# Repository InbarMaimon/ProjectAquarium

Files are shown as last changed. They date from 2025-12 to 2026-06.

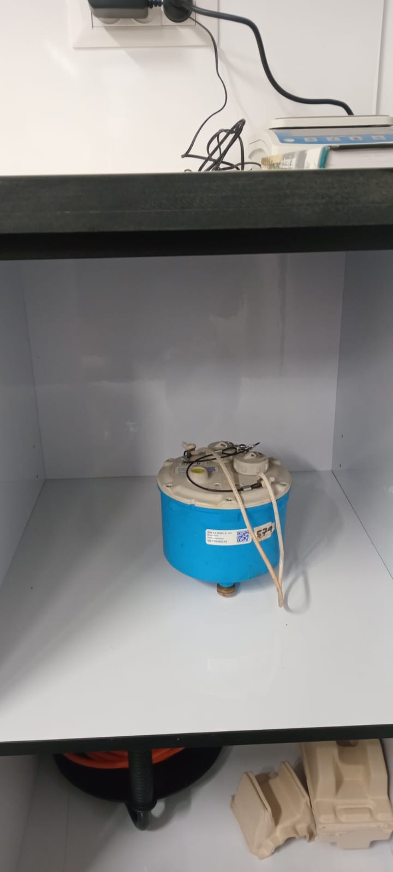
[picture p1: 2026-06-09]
images/seismographs/579-in-cabinet.jpeg

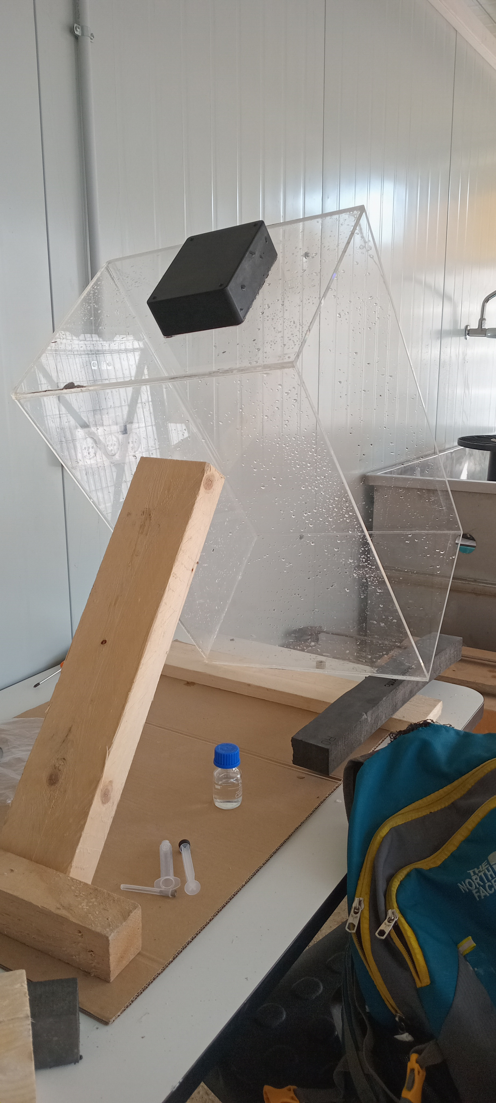
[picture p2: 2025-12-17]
images/aquarium/20251216_131820.jpg

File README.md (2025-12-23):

# Project Aquarium

Purpose:
Measure interaction between surfactants and capillary waves (ripples)

Structure:
- archive/      Junk that I don't have the heart to delete
- code/         Simulations, analysis
- data_raw/     Raw measurements
- data_proc/    Processed data
- design/       CAD, diagrams
- docs/         Theory
- images/       Photos of setup
- notes/         lab notes
- reports       Presentations, sum-ups, 
- results/      Figures, tables

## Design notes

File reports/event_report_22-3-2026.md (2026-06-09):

event report 22/3/2026

## short circuit
On the 18/3, Wednesday, I approached Tomer Brosh, the electrical engineer of the institute of earth sciences, and we connected the wiring of the motor circuit. Later in the lab I completed the circuit with the Raspberry Pi Pico (powered by my Thinkpad) and ran a short series of tests. mostly moving the coil statically up and down. The motor responded, though not cleanly. No further details.
While dissembling the circuit, I forgot to disconnect the power supply first. I loosened the screws that mount the motor and the power supply on the driver, and pulled out the + wire of the power supply. It touched the heads of the screws that mount the outputs of the motor. There was a short, part of the screw heads got brown, and the wire's terminal stuck to the head. I believe that at this point it disconnected the power and then separated the wire from the screw by applying a modest amount of force. Afterward I conncted the circuit again and it worked.

Measured today: 
resistance between the motor terminals: 1.6-1.7 ohm
diode resistance between the screws when the wires are disconnected is:

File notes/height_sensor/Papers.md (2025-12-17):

## A novel wave height sensor (Champan & Monaldo, 1993)
### 1.1 Questions

1. Accuracy of measurement, with respect to their reported sensitivity of $0.02 μ F ↔ 0.5 c m$ (small capacitance error corresponding to what is for us quite a large height error).
2. What is the circuit? Do we close it as usual from two sides of the wire? Is it a simple RC with square input or something more elaborate?
3. What exactly is the lower thickness limit of the oxide? How does leakage affect the capacitance, in a way that is not already reflected in the calibration curve? What is the optimal balance of minimizing leakage vs. maximizing capacitance in our system? How can we observe leakage from the standard capacitance measurement?
4. Self healing - shouldn’t happen exactly at the voltage of anodization? I’d think lower voltages will heal only a relatively deep crack. I saw $80V$ for anodization and $5V$ for healing.
5. On the other hand, why do we need a bias at all for valving? Isn’t it enough to input a positive bias for charging, with ground voltage for discharge?
6. How crucial will it be to know the exact salinity/chemistry of the water for calibration of the gauge? I think what we actually measure is the dielectricity of the excess water, and this I presume can depend strongly on its chemistry.
    
    \[The static dielectric constant (relative permittivity) of seawater is lower than pure water (around 80) and varies with temperature and salinity, but a common value used for open ocean conditions (around 20°C, 35 ppt salinity) is approximately 70-78\]
    
7. How important is it that the relationship between capacitance and local water height be linear? Isn’t a good (monotonic...) calibration curve enough?
8. Do we need fast charging for any reason but to save time?
9. What kinds of problems, noise sources etc. appear during simple measurements?
10. Verify no cross talks. In the paper they claim none down to $2 c m$ apart.

### 1.2 Idea

We want a non-intrusive way to measure wave height. The idea is to measure capacitance of a thin wire partly submerged in the water. If meniscus formed is small, the change in the wire capacitance (at the order of $μ F$ ) tracks the changes in the water height. Applying a DC offset signal keeps an anodizing process on, which self-heals damages to the oxide.

The wire is made of tantalum covered with its oxide ( $T a_2 O_5$ , made by submerging in citric acid), which is a good insulator.

The wire is connected to a circuit that feeds it with a square signal. Decay rate of the charge on the wire reports its capacitance. If the dielectric coating is uniform, the capacitance will change linearly with the height of the water.

### 1.3 Specifications

| parameter | size | comment |
| --- | --- | --- |
| tantalum wire diameter | $0.635 m m$ | the thinner the higher detection quality |
| corr. tensile strength | $70 k g m m ^{- 2}$ per $22 k g$ long. load | should taut the wire without tearing it  |

### 1.4 Manufacture process

1. Clean thoroughly in trichloroethane.
2. Rinse. Use gloves!
3. Put in citric acid under $0.5 m A c m ^{-2}$ (per total tantalum wire surface) DC up to $80 V$ , wherefrom the voltage is held constant, for __ minutes. **Smaller formation voltage generates thinner oxide layer.** Anodizing configuration:
    
    1. A trough long enough to hold the required wire including edge locking, with wire support glued to the bottom near both ends and terminal strips at the ends.
    2. A ground $6 m m$ stainless steel wire at the bottom of the trough.
    3. Rinsed tantalum wires strung near the top of the trough through the supports and terminals.
    4. $0.01\%$ citric acid solution that was stirred for several hours and then equilibrated over 24 hours.
    
    At constant voltage, perfect insulation will give 0 current. Hence minimal current (before excess defects develop) corresponds to best isolation. May try to replace electrolyte solution with cleaner one if leakage is above $0.005 m A c m ^{-2}$ (again proportional to total wire interface).
    
4. Rinse.
5. Cut the wire at the support positions.
6. Dry.
7. Observe metallic purple color. Hue indicates thickness, as the color is the result of thin film interference. [Observe effect of bending.]
    
    Remark 1. In the paper, they got $3.2 μ F m ^{-1}$ , I think per wire.

### 1.5 Circuit

The wire takes as an input a square waveform, that is, an alternating charge and discharge of the capacitor.

### 1.6 Digitization

Make sure that the digitization is good enough to measure the full scale height to voltage from the circuit.

### 1.7 Operation

1. Soak in target water for $30 m i n$ to relax initial drift processes, associated with crystallization of the oxide. \[Maybe I want to test that.\]

* As per their fig. 7, at $25 c m$ water depth and with a $3 c m$ diameter electronics tube at the bottom, the trend is already robustly linear at still water.

* Deviation from linear trend should be of the order of $± 0.05 μ F$ for capacitance of $∼ 0.1 - 10 μ F$. They report an error of 0.5 c m for static depth in the range $25 - 300 c m$ . We need something more sensitive.

* Frequency response should drop down $∼ 3 d B$ at $16 H z$, so we do not expect to measure very small ripples.  

* We should recalibrate the system once every two weeks or so to see that the capacitance-to-height slope didn’t change significantly.

* Notice not to allow resonance between capillaries and wires.

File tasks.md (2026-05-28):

### Back to Business
Draw on some board the various tasks that need to be handled. That would be:
  a. The Boson
  b. The big container
  c. The seismic analysis
  d. The height sensor
  e. The aquarium's structure
  f. The wave maker
  g. The alternative height sensor

### Administrative
1. Access to printer.
2. On Sunday/Monday morning, talk to Helena about internet connection in the shed.

### General
1. Learn git and absorb into workflow.

### Science
1. Overview of spectrum of sea water capillary with various surfactants.
1. Finish reading Zappa's paper about amplitudes/slopes of capillary waves.

### Boson
1. Go through the state of the code, write down here what we can and cannot do.
2. A new pin for the box?
3. See that I know where the parts are.

### Aquarium
1. Clean the shed.
2. Go through the code, see where we're at.
3. What was the state of the vibration analysis?
4. Understand how to lock the aquarium in place, and width of bridges.

### Wave maker
1. Review the parts that we have.
2. Make a complete scheme of the plunger solution.
3. Once we settle on a complete solution, including exact parts, talk to Tomer/Yosi again about it.
4. Reach out to Itsik for construction

### Height sensor
1. Verify that the capacitive gauge satisfies our sensitivity requirements.
2. Review the logs from the height sensor manufacturing.
3. Capacitive gauge making.
 
```mermaid
flowchart TD
    START[Start] --> HEIGHT([Height sensor: physical requirements & pricing])
    START[Start] --> WM_T([Wave making theory])
    START[Start] --> STG[Permanent stage for the aquarium]

    STG --> HB[Bridge for the height sensor]
    STG --> WMB[Bridge for the wave maker]

    HEIGHT --> SENS_SEL{Select Sensor Type}
    
    WM_T --> WM_SD[required stroke depth: ~2-20mm];
    RG1[research goals: inspect gravity-capillary waves] --> WM_GF[required frequencies: ~5-30Hz];
    RG2[research goals regarding type of interactions] --> Meas_MD[measurement distance where standing waves vanish: 30cm is more than enough]

    WM_T --> Meas_MD
    WM_SD --> WM_CM[Choose motor];
    WM_GF --> WM_CM;
    WM_CM --> WM_F[Design system];
    WM_CM --> WM_C[Choose controller]
    WM_F --> WM_G[Get pricing];
    WM_G --> WM_H[Build system];

    SENS_SEL -->|Capacitive| CAP_DESIGN[Design]
    SENS_SEL -->|Laser| LASER([Design])

    CAP_DESIGN --> COMM_DES[Design<br/>connections]
    CAP_DESIGN --> CAP_LEN[Decide wire<br/>length & quantity]
    CAP_DESIGN --> ELEC_DES[fit<br/>terminal strip]
    CAP_DESIGN --> HOLD_SOL[Decide<br/>holder solution]

    WM_C --> COMM_DES[Design<br/>connections]

    CAP_LEN --> TROUGH_DER[Derive<br/>trough length]
    
    TROUGH_DER --> PROCURE[Buy pipe,<br/>SS rod/wire, holder<br/>material, citric acid]
    ELEC_DES --> PROCURE
    HOLD_SOL --> PROCURE
    
    PROCURE --> CUT_PARTS[Cut trough<br/>& holders, leave<br/>rod path]
    
    CUT_PARTS --> GLUE_HOLD[Glue<br/>holders]
    
    GLUE_HOLD --> GET_VSRC[Get smart<br/>voltage source]
    GLUE_HOLD --> GET_H2O[Get<br/>pure water]
    
    GET_VSRC --> GND_ROD[Place ground<br/>SS rod & connect<br/>to source]
    GET_H2O --> GND_ROD
    
    GND_ROD --> WIRE_MOUNT[Mount<br/>wires on holders &<br/>connect to terminal]
    
    WIRE_MOUNT --> TERM_CONN[Connect<br/>terminal to source]
    
    TERM_CONN --> OBSERVE[Observe<br/>result]

    LASER --> COMM_DES
    LASER --> RANGE[Height range: 10-30mm]
    LASER --> SPOT[Spot diameter: 1-5mm]
    LASER --> VIB_RES[Stability in frequency range: 5-30Hz]
    LASER --> TRANS[Reflects well from water?]
    LASER --> SAMP[Verify sampling rate]
```

### Camera
1. Study camera software.
2. Measure width of container.
3. Order/build mount (including weight) + pitch axis + how to measure the pitch.
4. Verify camera screws fine to mount.

### Possible schedule clashes
I think there should be none. The gauge should be non-intrusive, but the assemble is very simple.

## periodically

### daily note
- what was done
- what is to be done tomorrow

### git
Edit → Add → Commit → Push

This is the project backup workflow. All tracked files, including moved or renamed files, are preserved both locally and on GitHub.

1. Daily / session work
Edit files as needed (code, documentation, data notes).
Add new files or moved files to Git tracking:

    git add <file_or_folder>

or to add everything modified/untracked:

    git add .gitignore README.md docs project_env.sh   // ignore until we have a stable version

2. Commit changes
Commit logically grouped changes with a clear message:

    git commit [--amend] -m "Daily: [changes I've made]"

Commit at the end of each logical task or end-of-day. This keeps your history clean.

3. Push to GitHub
Upload local commits to the online backup:

    git push [--force-with-lease // if --amend was done.]

After this, your local repository and the remote repository are in sync.
GitHub now acts as a full backup of all tracked files and history.

4. Optional: Pull before starting work on another machine
If you work on multiple machines:

git pull

Ensures you have the latest state before editing.

5. Best practices

- Commit small, logical changes rather than massive, vague commits.
- Track only what matters (use .gitignore to skip temporary files, generated data, and .obsidian).
- Do not push large raw data files if they exceed GitHub limits; keep them local or use Git LFS.
Tag stable milestones (optional):

git tag v1.0
git push --tags

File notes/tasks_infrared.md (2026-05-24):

## Capacitance gauge 
- report the anodization process.
- add block diagram with comments of capacitor to computer line
- add pictures of the parts

## Infrared:

- find a replacement for the missing screw

- ask Maly about purchase of towels, IPA99, clean air pressure bottles.

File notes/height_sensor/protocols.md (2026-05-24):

### Citric acid making protocol
#### Materials:
- goggles
- gloves
- coat
- solid citric acid
- small powder holder
- fine-scale weight
- acid container
- acid waste collector
- water source

#### Procedure:
1. put coat, eye shield, gloves.
2. weigh 0.1g of citric acid.
3. weigh 1 liter of tap/deionized water
4. pour a small amount of water
5. put the acid
6. wash the rest of acid with water
7. seal the bottle and shake
8. pour the rest of the water
9. seal and shake
10. acid holder to garbage
11. make sure you left enough space in the bottle for pressure to not overbuild,
or othewise loosen the lid slightly.
12. mix on the shaker for an hour
13. take of the shaker, let it stand the night in the fume hood.
Might be slightly open.

### Anodization protocol
#### Materials:
- goggles
- gloves
- coat
- trough with tantalum wires mounted straight.
- power generator with power cable.
- black and red crocodile cables
- ampermeter
- male-male cables as needed
- acetone
- acid in container
- clean paper towel
- acid waste collector
- meter
- pliers or 1 plier and 1 melkhatzayim

#### Procedure:
1. Straighten the wires as much as possible.
2. Cut large enough pieces to fit nicely in the holder + exposed side.
3. Put goggles and gloves.
4. Clean everything with acetone and tap water. Also gloves.
5. Put the trough in the hood on a clean plate, preferably with a clean paper in between.
6. Put the power generator beside it but away, so that no acid spill can easily reach it.
7. Mount the wires in the holder.
8. Gently put the holder in place and close the screws.
9. Write formation voltage used.
10. Connect the power generator to socket, set max current on required mA limit value (can be more exact if power generator allows) and voltage on maximum.
11. Fill the trough with citric acid.
12. Connect the + to the tantalum and the - to the stainless steel. 
13. Connect a resisor in series.
14. Connect a voltmeter/raspberry pi voltage sensor on it.
15. Turn on the ports.
16. Write the time of start.
17. Write time of formation voltage.
18. Write time of minimum current.
19. (If we go for anodization sealing, fill a small amount of citric acid back into the trough and put the end of the cut wires in it, connect + and - and anodize up to formation voltage.)
20. Disconnect the circuit and carefully collect the + and - wires. If needed, clean them with a damp paper towel, then with a dry one. 
21. Disconnect the power generator from socket. If needed, clean cable and generator with damp and dry paper.
22. If anodization is done, put generator in place.
23. Prepare a clean sheet of paper for to put cleaned trough parts and wires to dry.
24. Spill the wasted acid to acid collector. Mark it if needed.
25. Disassemble the trough. Be careful with the anodized wires!
26. Clean the trough parts with tap/deionized water.
27. Store/pack acid container.
28. Return goggles, coat to place.

### Quick capacity check
#### Material:
- gloves
- a small cup
- a capacitance meter and +- wires
- anodized tantalum wire
- meter/ruler
- deionized/tap water source
#### Procedure:
1. Cut the anodized wire.
2. Cover the end with some temporary isolator.
3. Rinse the wire in deionized water.
4. Prepare a cup with tap water in it.
5. Connect anodized wire to +.
6. Connect an exposed wire to -.
7. If tips are not isolated, make sure the multimeter works at voltage below 1V, so that the natural oxide at the tip can serve as a (partial) isolation.
8. Formation voltage vs. capacitance:
   1. 60V -> ~ (2.0-6.8)[nF/mm]
   2. 80V -> ~ (1.5-5.1)[nF/mm]
   3. 120V -> ~ (1.0-3.4)[nF/mm] (!!!Avoid because of risk of scintillation!!!)

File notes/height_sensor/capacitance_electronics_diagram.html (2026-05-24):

## Aquarium Sensor — Electronics Block Diagram

flowchart TB subgraph SENSORS["Sensors (in aquarium)"] TA1["Ta wire 1\nCapacitor"] TA2["Ta wire 2\nCapacitor"] TA3["Ta wire 3\nCapacitor"] end subgraph BOX["Electronics box (on mounting plate)"] CDC["CDC Board\nScioSense PCAP04\n\nMeasures capacitance\nof each Ta wire"] PICO["PS2→USB Interpreter\nPicoprog\n\nConverts CDC output\nto USB HID"] end PC["Windows Computer\nReads USB HID data"] TA1 -->|"analog\n(short wire)"| CDC TA2 -->|"analog\n(short wire)"| CDC TA3 -->|"analog\n(short wire)"| CDC CDC -->|"SPI / I²C\n(digital)"| PICO PICO -->|"USB\n(digital, long cable OK)"| PC style SENSORS fill:#fff3e0,stroke:#e65100,stroke-width:2px,color:#333 style BOX fill:#e3f2fd,stroke:#01579b,stroke-width:2px,color:#333 style TA1 fill:#ffccbc,stroke:#bf360c,color:#333 style TA2 fill:#ffccbc,stroke:#bf360c,color:#333 style TA3 fill:#ffccbc,stroke:#bf360c,color:#333 style CDC fill:#bbdefb,stroke:#01579b,color:#333 style PICO fill:#bbdefb,stroke:#01579b,color:#333 style PC fill:#c8e6c9,stroke:#1b5e20,color:#333

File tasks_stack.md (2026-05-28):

### Now
We want to estimate the physical parameters of the capillary waves we set to observe.
For this we need to know:
1. Their height spectrum - the expected amplitude as a function of wavenumber/frequency.
2. In particular, if and where there's a high cutoff.
Next, we want to understand the theoretical dispersion so we need to:
1. Implement the code for a fitting model (happened?).
2. Estimate the parameter values (complex elasticity etc.) for various conditions: compile a small library of parameters by surfactant type.
3. Plot the contribution of various components, if extractable, against wavenumber/frequency.

### Wendesday morning
1. To Mali if she has a documentation of what I've bought from the main warehouse.
2. Go to the main warehouse and get air, Isopropyl alcohol (IPA) 99% and fitting towels. Cotton swab?
3. Call Shahaf or Eran about the screw.
4. Clean the box's window.

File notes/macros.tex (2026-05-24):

% ============================================================
% Macros (converted from macros.lyx)
% ============================================================

\newcommand{\entropy}{\eta}

\newcommand{\surfaceTension}{\tau}
\newcommand{\sTension}{\surfaceTension}

\newcommand{\surfaceWaterDensity}{\rho}
\newcommand{\sDensity}{\surfaceWaterDensity}

\newcommand{\stressTensor}{\sigma}

\newcommand{\surfacePressure}{p_{0}}
\newcommand{\sPressure}{\surfacePressure}

\newcommand{\surfactantBulkConcentration}{c}
\newcommand{\sBulkCo}{\surfactantBulkConcentration}

\newcommand{\surfactantSurfaceConcentration}{s}
\newcommand{\sSurfCo}{\surfactantSurfaceConcentration}

\newcommand{\velocityPotential}{f}
\newcommand{\vPotential}{\phi}
\newcommand{\vStream}{\psi}

\newcommand{\kinematicViscousity}{\nu}

\newcommand{\kTravel}{k_{p}}
\newcommand{\kevanescentn}{k_{e,n}}
\newcommand{\kEvanescentn}{k_{e,n}}

\newcommand{\aquariumHeight}{H}
\newcommand{\aquariumLength}{L}
\newcommand{\aquariumWidth}{W}
\newcommand{\aHeight}{\aquariumHeight}
\newcommand{\aLength}{\aquariumLength}
\newcommand{\aWidth}{\aquariumWidth}

\newcommand{\baseVel}{u}

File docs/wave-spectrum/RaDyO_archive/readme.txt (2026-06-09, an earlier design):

**********
**README**
**********

The attached '.mat' files contain full spectra and probability density functions computed from the short wave fields observed during the 2008 RaDyO campaign. Water surface elevation time series from the Riegl lidar are provided (with dimensions of meters).

For all files:

k - wavenumber in rad/m
B - omnidirectional saturation spectrum in rad
ustar - friction velocity u* in m/s

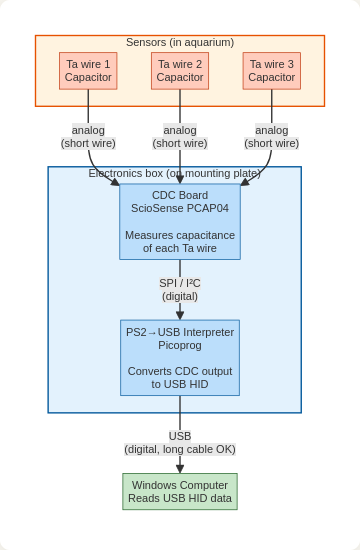
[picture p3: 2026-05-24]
notes/height_sensor/capacitance_electronics_diagram.png

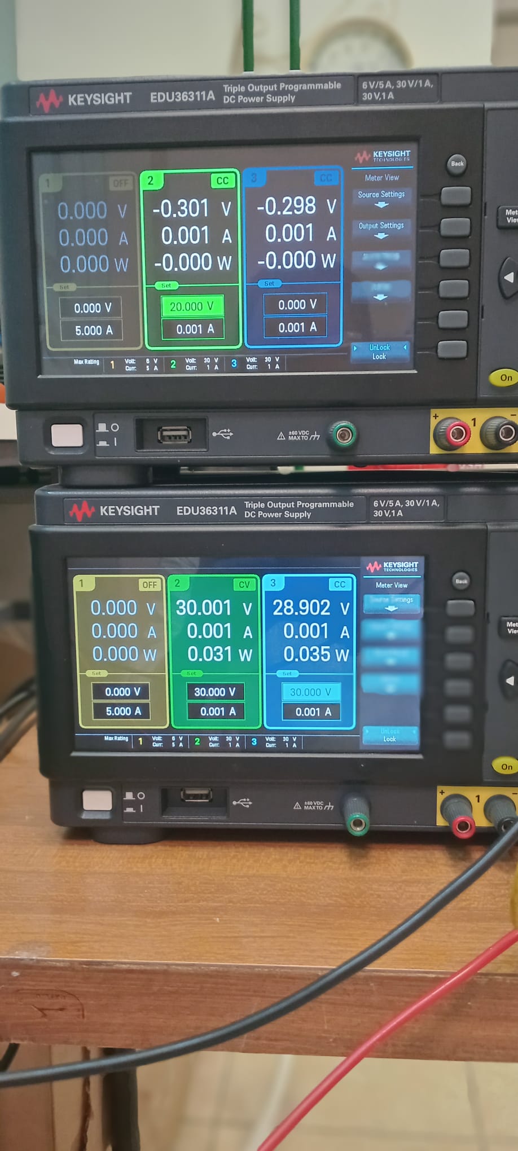
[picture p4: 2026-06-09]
images/anodization/typical-reading-of-generator.jpeg

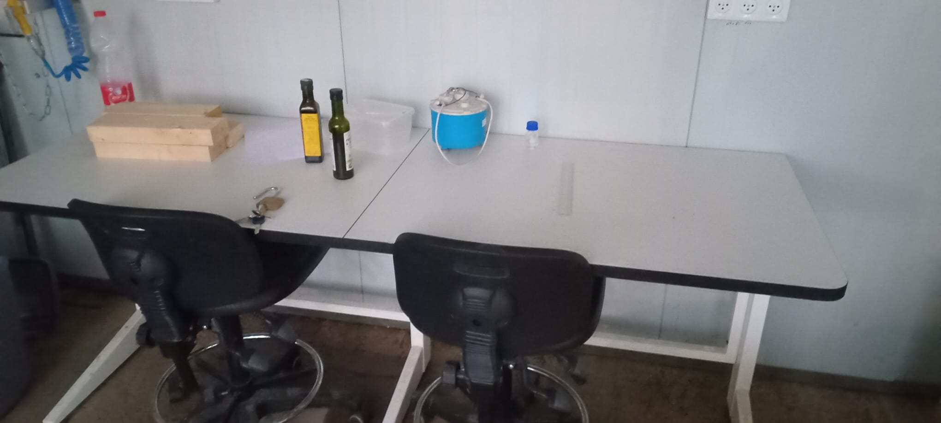
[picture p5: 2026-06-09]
images/seismographs/583-on-desk.jpeg

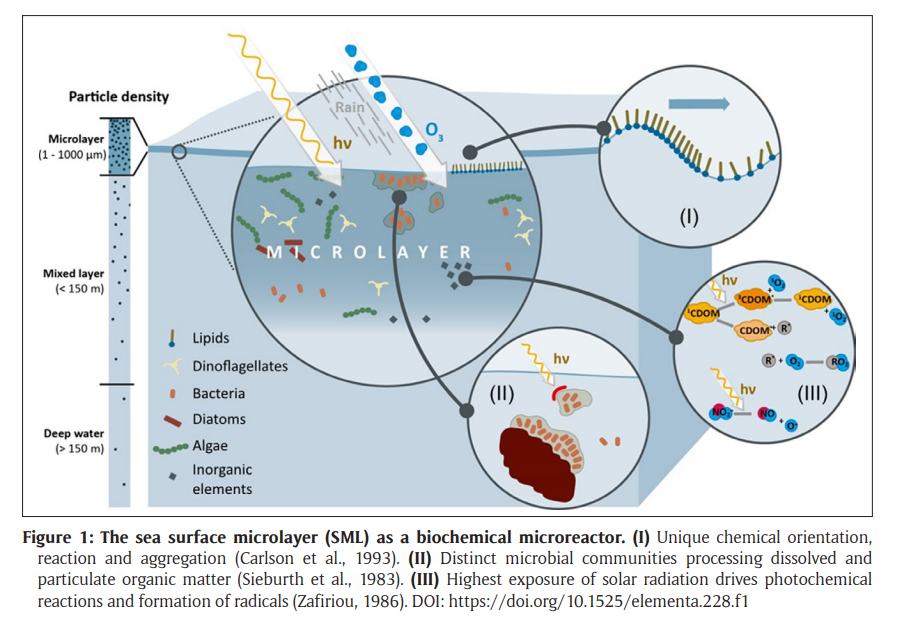
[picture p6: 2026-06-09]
docs/Wurl - Sea surface microlayer in a changing ocean - figure 1.png

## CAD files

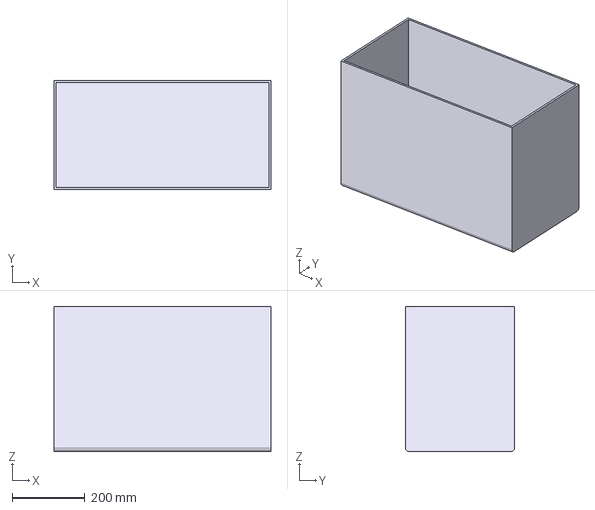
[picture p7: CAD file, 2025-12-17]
design/aquarium/aquarium-Body.step
598.5 x 301.0 x 400.0 mm

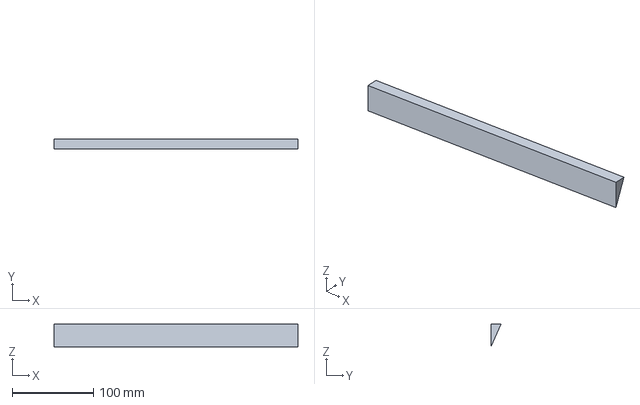
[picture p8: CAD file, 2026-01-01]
design/wave_maker/wavemaker_model.FCStd
300.0 x 12.4 x 27.8 mm

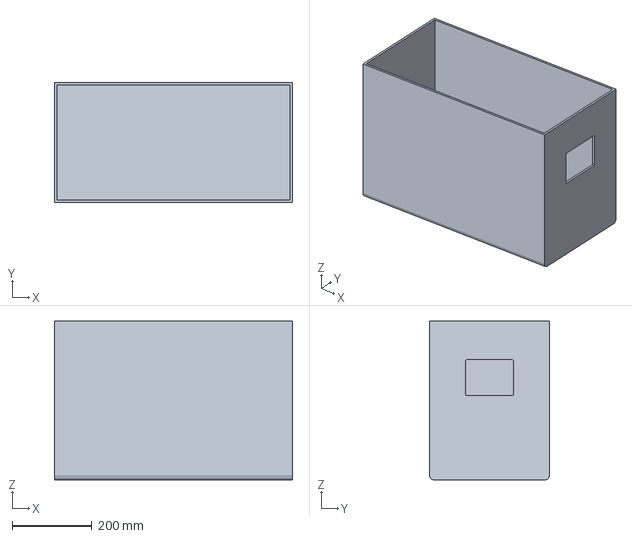
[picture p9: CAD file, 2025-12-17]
design/aquarium/aquarium.FCStd
598.5 x 301.0 x 399.0 mm

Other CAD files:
design/aquarium/aquarium-Body.3mf

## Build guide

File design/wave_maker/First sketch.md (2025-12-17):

1. Stepper motor generates constant roll:
    1. Understand size, shape, weight and price.
    2. Understand whether comes with a controller, or cont. comes separately, and how I communicate with the controller.
    3. If needed: purchase an Arduino and learn how to work with it.
    
2. Crankshaft converts to linear motion:
    1. Learn FreeCad and download/make a model.
    2. Order two bearings that connect the conrod to the piston/screw and to the disc.
    3. Check weights of suggested plungers and verify that the piston can connect to them and that the plastic carries well the load.
    
3. Connect a plunger head:
    1. Find a vertical plunger model that excites minimal number of modes.
    2. Understand how to mount it on the piston.
    3. Print crankshaft somewhere in the university and assemble.

4. Mount on aquarium:
    1. Clean the aquarium.
    2. Glue it - how?
    3. Plan a bridge with mount for the motor and crankshaft.
    4. Get it.

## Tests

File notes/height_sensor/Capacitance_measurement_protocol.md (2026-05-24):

## Capacitance measurement protocol

### Preliminary requirements:
- The capacitive gauge wires are mounted stretched in a robust manner.
- How to read a data file.
- How is the data saved in real time?
- What is the external offset? Is it stable under mild perturbations? (introduce manually)
- Can I measure external offset during a run?

### Linearization

### Run
- External capacitive offset: measure once, before experiment, at varying temperatures if possible. Make sure that the physical configuration doesn't change significantly during the experiment.

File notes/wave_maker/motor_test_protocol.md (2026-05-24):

## order of assemble:
1. Make a clean surface with room for motor, driver and controller.
2. Put the power supply in an accessible position far from everything else.
3. Put the motor gently with pin up.
4. Put the driver nearby.
5. Connect the PS wires to the driver. Make sure that - (blue) goes to GND and + (brown) goes to VIN. Screw them.
6. Connect the motor wires to the driver. Make sure that OUTA (red) goes to OUTA and OUTB (black) goes to OUTB.
7. Put the Pico nearby, legs up.
8. Wiring:
  GP0  → [brown] → 810-01 PWM pin
  GP1  → [orange] → 810-01 DIR pin
  GP2  → [white] → 810-01 RESET pin  (active LOW: pull low to disable driver)
  GND  → [black] → 810-01 Logic GND
9. Connect Pico to computer.
10. Connect Pico to VS code interface.
11. Download current image of the test files.
12. Verify that everything is there using os.listdir().
13. Connect power.
14. Set duty to 0, enable, set duty to 5%, observe lift.
15. Play.

## order of dissemble:
1. Set duty to 0, observe the magnet falls back to place, disable.
2. Assemble in reverse.

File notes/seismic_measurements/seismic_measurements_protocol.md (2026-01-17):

protocol

14.1 ~14:00 - One day on the table / in the lab on table
15.1 14:00 - Move one whole meter along each axis, then return to place.
+ three days on the table / three days in the lab on table
18.1 14:00
one day on the ground inside shed / in the lab on the ground

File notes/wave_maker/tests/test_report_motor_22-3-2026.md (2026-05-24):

I connected the circuit. Motor was placed with its pin up.
Initially I switched the GND and RESET wires. Rewired correctly afterward.
I tried the sine function input at 4.3% offset, 2% (voltage) amplitude and 1000ms period. The motor moves up and down regularly but nonsinusoidally, with the uplift looking sharper than the downglide and the movement overall rather constant in velocity.
I also tried 4.3% 4% 40ms and 20ms. The movement looks and sounds irregular.

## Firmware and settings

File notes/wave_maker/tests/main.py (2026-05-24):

"""
moticont_hold.py
----------------
Raspberry Pi Pico 2W  →  Moticont 810-01 driver  →  GVCM-015-025-01

Wiring:
  GP0  → [brown] → 810-01 PWM pin
  GP1  → [orange] → 810-01 DIR pin
  GP2  → [white] → 810-01 RESET pin  (active LOW: pull low to disable driver)
  GND  → [black] → 810-01 Logic GND

PWM frequency : 20 kHz  (inaudible, well within driver 50 kHz max)
Control       : USB serial (115200 baud) — connect with any terminal
                e.g.  screen /dev/ttyACM0 115200
                      PuTTY, Thonny REPL, etc.

Serial commands (case-insensitive):
  enable          - release RESET, driver becomes active
  disable         - assert RESET, driver disabled (coil de-energised)
  duty <0-100>    - set PWM duty cycle as a percentage  e.g. "duty 35"
  dir <0|1>       - set direction  (0 = OUTB→OUTA, 1 = OUTA→OUTB)
  status          - print current duty, direction, and enable state

Notes:
  - This is open-loop. Start with a LOW duty cycle (~10-20%) and increase
    slowly until the coil holds position against gravity. Exceeding the
    motor's continuous current rating will cause overheating.
  - GVCM-051-025-01 continuous force is modest; don't run at 100% duty
    for extended periods without checking motor temperature.
  - The RESET pin is active-LOW on the 810-01. Driving GP2 HIGH releases
    the driver; driving it LOW disables it.
"""

import sys
import select
from tests_vc import handle_line

# ---------------------------------------------------------------------------
# Boot banner
# ---------------------------------------------------------------------------
print("=" * 50)
print("  Moticont GVCM-015-025-01 / 810-01 hold controller")
print("  Pico 2W  |  20 kHz PWM  |  GP0=PWM  GP1=DIR  GP2=RESET")
print("  Driver is DISABLED on boot. Send 'enable' to start.")
print("  Type 'status' for current settings.")
print("=" * 50)

# ---------------------------------------------------------------------------
# Main loop — non-blocking USB serial read
# ---------------------------------------------------------------------------
buf = ""

while True:
    # Poll stdin without blocking (works on Pico USB serial)
    if sys.stdin in select.select([sys.stdin], [], [], 0)[0]:
        ch = sys.stdin.read(1)
        if ch in ("\r", "\n"):
            if buf:
                handle_line(buf)
                buf = ""
            else:
                continue
        elif ch == "\x08":   # backspace
            buf = buf[:-1]
        else:
            buf += ch

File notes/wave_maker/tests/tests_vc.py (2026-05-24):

import sys
import select
import time
import math
from machine import Pin, PWM

# ---------------------------------------------------------------------------
# Pin assignments
# ---------------------------------------------------------------------------
PIN_PWM   = 0   # GP0 → 810-01 PWM input
PIN_DIR   = 1   # GP1 → 810-01 DIR input
PIN_RESET = 2   # GP2 → 810-01 RESET input (HIGH = run, LOW = disabled)

# ---------------------------------------------------------------------------
# PWM configuration
# ---------------------------------------------------------------------------
PWM_FREQ_HZ = 20_000   # 20 kHz — inaudible, within driver spec

# ---------------------------------------------------------------------------
# Default motion parameters  (edit these as a starting point)
# ---------------------------------------------------------------------------
DEFAULT_DUTY_PERCENT = 0    # Start at 0%; increase via serial once enabled
DEFAULT_DIRECTION    = 1    # 1 = OUTA→OUTB; pushes outward

# ---------------------------------------------------------------------------
# Hardware initialisation
# ---------------------------------------------------------------------------
pwm = PWM(Pin(PIN_PWM))
pwm.freq(PWM_FREQ_HZ)

dir_pin   = Pin(PIN_DIR,   Pin.OUT)
reset_pin = Pin(PIN_RESET, Pin.OUT)

# Helpers
def _duty_u16(percent: float) -> int:
    """Convert 0–100 % to 0–65535 for machine.PWM.duty_u16()."""
    return int(max(0.0, min(100.0, percent)) / 100.0 * 65535)

# ---------------------------------------------------------------------------
# State
# ---------------------------------------------------------------------------
state = {
    "enabled": False,
    "duty":    DEFAULT_DUTY_PERCENT,
    "dir":     DEFAULT_DIRECTION,
}

def _apply_state():
    """Push current state to hardware."""
    dir_pin.value(state["dir"])
    pwm.duty_u16(_duty_u16(state["duty"]) if state["enabled"] else 0)
    # RESET pin: HIGH = driver active, LOW = driver disabled
    reset_pin.value(1 if state["enabled"] else 0)

# Start safe: driver in reset, zero PWM
_apply_state()

# ---------------------------------------------------------------------------
# Command handlers
# ---------------------------------------------------------------------------
def cmd_enable(_args):
    state["enabled"] = True
    _apply_state()
    return f"Driver ENABLED  |  duty={state['duty']:.1f}%  dir={state['dir']}"

def cmd_disable(_args):
    state["enabled"] = False
    _apply_state()
    return "Driver DISABLED  (coil de-energised, RESET asserted)"

def cmd_duty(args):
    if not args:
        return "ERROR: usage:  duty <0-100>"
    try:
        val = float(args[0])
    except ValueError:
        return "ERROR: duty value must be a number 0–100"
    if not (0 <= val <= 100):
        return "ERROR: duty must be between 0 and 100"
    state["duty"] = val
    if state["enabled"]:
        pwm.duty_u16(_duty_u16(val))
    return f"Duty set to {val:.1f}%  {'(applied)' if state['enabled'] else '(staged — enable driver to apply)'}"

def cmd_sine(args):
    """sine [center_%] [amplitude_%] [period_ms]
    Oscillates duty cycle as:  center + amplitude * sin(t)
    Defaults: center=4  amplitude=1  period=2000ms
    Send any serial character to stop.
    """

    try:
        center    = float(args[0]) if len(args) > 0 else 4.0
        amplitude = float(args[1]) if len(args) > 1 else 1.0
        period_ms = float(args[2]) if len(args) > 2 else 2000.0
    except ValueError:
        return "ERROR: usage:  sine [center_%] [amplitude_%] [period_ms]"
 
    if not state["enabled"]:
        return "ERROR: driver not enabled — send 'enable' first"
 
    max_duty = center + amplitude
    if max_duty > 25:
        return f"ERROR: center+amplitude={max_duty:.1f}% exceeds 25% continuous limit at 24V"
 
    print(f"Sine running: center={center}%  amplitude={amplitude}%  period={period_ms}ms")
    print("Send any key to stop.")
 
    step_ms   = 1                           # update every 1ms → 1kHz
    steps     = int(period_ms / step_ms)    # steps per full cycle
    i         = 0
 
    while True:
        # Check for keypress to stop
        if sys.stdin in select.select([sys.stdin], [], [], 0)[0]:
            sys.stdin.read(1)               # consume the character
            break
        angle    = 2 * math.pi * (i % steps) / steps
        duty_pct = center + amplitude * math.sin(angle)
        pwm.duty_u16(_duty_u16(duty_pct))
        time.sleep(step_ms / 1000)
        i += 1
 
    # Restore previous duty on exit
    pwm.duty_u16(_duty_u16(state["duty"]))
    return f"Sine stopped. Duty restored to {state['duty']:.1f}%"

def cmd_dir(args):
    if not args or args[0] not in ("0", "1"):
        return "ERROR: usage:  dir <0|1>"
    state["dir"] = int(args[0])
    if state["enabled"]:
        dir_pin.value(state["dir"])
    return f"Direction set to {state['dir']}  {'(applied)' if state['enabled'] else '(staged — enable driver to apply)'}"

def cmd_status(_args):
    lines = [
        "--- Status ---",
        f"  Enabled  : {state['enabled']}",
        f"  Duty     : {state['duty']:.1f}%",
        f"  Direction: {state['dir']}  (0=OUTB→OUTA  1=OUTA→OUTB)",
        f"  PWM freq : {PWM_FREQ_HZ} Hz",
    ]
    return "\n".join(lines)

COMMANDS = {
    "enable":  cmd_enable,
    "disable": cmd_disable,
    "duty":    cmd_duty,
    "sine":    cmd_sine,
    "dir":     cmd_dir,
    "status":  cmd_status,
}

def handle_line(line: str):
    parts = line.strip().lower().split()
    if not parts:
        return
    verb, args = parts[0], parts[1:]
    if verb in COMMANDS:
        response = COMMANDS[verb](args)
    else:
        response = (
            "Unknown command. Available: enable | disable | duty <0-100> "
            "| dir <0|1> | status"
        )
    print(response)

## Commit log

2025-12-17 Initial project structure and documentation
    [aquarium-Body.3mf, aquarium-Body.step, aquarium.FCStd]
2026-01-01 Weekly snapshot; Nonspecific.
    [wavemaker_model.FCStd]
